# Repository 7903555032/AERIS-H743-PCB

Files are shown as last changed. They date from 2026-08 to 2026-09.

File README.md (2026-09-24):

# AERIS-H743 Hardware

# AERIS — Advanced Embedded Research & Intelligent Systems

A 6-layer STM32H743-based embedded development and flight-control/data-logging PCB designed as a practical hardware-design and PCB-layout project.

## Project Status

🚧 **Practice / Learning Project — Hardware Design Completed**

The PCB design phase is complete. This project is primarily a practical exercise to learn and apply professional PCB design concepts using KiCad, including schematic design, component selection, multi-layer stackup, component placement, power distribution, signal routing, high-speed interfaces, sensor interfacing, and design-rule checking.

This is **not a production-ready or professionally validated flight controller**. The design may contain mistakes or areas that require further review, optimization, and hardware validation.

The main goal of this project is to gain hands-on experience designing a complex **6-layer embedded PCB** from the ground up.

## Hardware Features

- STM32H743VIT6 — ARM Cortex-M7, up to 480 MHz
- 6-Layer PCB
- USB Type-C
- SPI / QSPI External Flash
- microSD via SDMMC
- ICM-42688-P IMU
- BME280 Environmental Sensor
- RTC
- INA219 Power Monitor
- CAN FD
- RS485
- GPS UART
- 4× ESC PWM Outputs
- SWD Debug Interface
- 3.3 V / 5 V Regulated Power Architecture

## PCB Architecture

- **L1 — Components + Critical Signals**
- **L2 — Ground Plane**
- **L3 — Power Distribution**
- **L4 — Signal Routing**
- **L5 — Ground Plane**
- **L6 — Bottom Signals + Selected Components**

## Communication Interfaces

- CAN FD
- RS485
- GPS UART
- USB
- SPI / QSPI
- I²C
- SDMMC

## PCB Design Goals

The main purpose of this project is to practice designing a relatively complex embedded PCB and understand how different parts of a real hardware system interact.

The design focuses on:

- 6-layer PCB architecture
- Power distribution
- Ground-plane design
- High-speed digital interfaces
- MCU placement and routing
- Sensor placement
- IMU placement considerations
- QSPI and SDMMC routing
- USB differential-pair routing
- CAN FD and RS485 interfaces
- ESC interfaces
- Thermal and mechanical considerations
- Custom KiCad symbols, footprints and 3D models
- PCB Design Rule Checking (DRC)
- Manufacturing preparation

## Project Structure

```text
AERIS-H743/
│
├── KiCAD/
│   └── AERIS-H743-PCB/
│       ├── AERIS-H743-PCB.kicad_pro
│       ├── AERIS-H743-PCB.kicad_sch
│       ├── AERIS-H743-PCB.kicad_pcb
│       ├── MCU_Core.kicad_sch
│       ├── POWER.kicad_sch
│       ├── Memory&Storage.kicad_sch
│       └── sensors.kicad_sch
│
├── Libraries/
│   ├── Symbols/
│   ├── Footprints.pretty/
│   └── 3D/
│
├── Documentation/
│
├── Datasheets/
│
└── README.md

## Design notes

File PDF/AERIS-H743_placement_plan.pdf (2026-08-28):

# AERIS-H743

## PCB component placement plan — pre-routing

Fabrication-oriented placement plan for the 6-layer, 5-inch-class quadcopter PCB. Zones and priorities are derived from the confirmed mechanical spec (160mm hole-to-hole diagonal, 46x46mm hub, 20mm arms) and the established schematic architecture. Anything not yet specified in the project (exact battery current, motor/ESC current draw, U1 switching frequency, firmware axis convention) is marked OPEN/NEEDS VERIFICATION rather than assumed.

# 1. Per-component placement table

Ref | Component | Zone | Orientation/relation | Reason
J1 | XT30 connector | Power entry | Board edge, cable exit pointing outward | First point of contact — needs external cable access
Q1 | AO3407A P-FET | Power entry | In line between J1 and F1, within 5mm of both | Reverse-polarity protection must be first in the chain, no detours
R1 | 10k gate pulldown | Power entry | Directly at Q1 gate pin | Minimize gate trace length
F1 | Fuse 2A PPTC | Power entry | In line, within 5mm of Q1 and R26 | Series element, keep the high-current path straight
D1 | SMF26A TVS | Power entry | Directly across the F1-R26 junction to nearest GND via | Needs shortest possible path to ground to clamp effectively
R26 | Shunt 20mOhm | Power entry | In line, Kelvin-sense traces to U10 kept short and symmetric | Current-sense accuracy depends on clean, undisturbed sense trace routing
C1, C2 | Buck input caps 10uF | Power conversion | Within 3mm of U1 VIN pin | High-frequency input decoupling, distance directly increases loop inductance
U1 | AP63205WU buck | Power conversion | Oriented so SW node/inductor loop is compact and away from IMU zone | Switching node is the primary EMI source on the board
L1 | Buck inductor | Power conversion | Immediately adjacent to U1 SW pin, shortest possible SW trace | SW node trace should be as short and wide as practical — high dv/dt
C3 | Buck output cap 22uF | Power conversion | Within 3mm of L1 output / U1 FB divider | Output ripple filtering, close to the node it filters
R2, R3 | FB divider | Power conversion | Tight to U1 FB pin, away from SW node/inductor | FB is a sensitive high-impedance node — noise pickup here destabilizes regulation
C4 | Bootstrap cap 100nF | Power conversion | Directly between U1 BOOT and SW pins | Bootstrap caps must be immediately adjacent to their pins by design
U9a | AP2112K-3.3 digital LDO | Power conversion | Between buck output and MCU zone | Shortens the +3V3 digital distribution path
U9b | AP7343-33W5-7 sensor LDO | Power conversion | Between buck output and IMU/sensor zone, physically separated from U9a | Keeps sensor rail regulation independent and close to what it feeds
C5a-d | LDO in/out caps 1uF | Power conversion | Directly at each LDO IN/OUT pin | Standard LDO stability requirement — distance affects transient response
U10 | INA226 | Power entry | Adjacent to R26, Kelvin sense traces direct | Sense accuracy depends on undisturbed direct connection to shunt
C7 | INA226 decoupling 100nF | Power entry | At U10 VCC pin | Standard IC decoupling
J2 | USB-C receptacle | USB zone | Board edge, connector shell grounded to nearest edge copper | Needs external cable access
U2 | USBLC6-2SC6 ESD | USB zone | Between J2 and the D+/D- trace path, within 3mm of J2 pins | ESD protection must intercept transients before the trace, at the connector
R4, R5 | USB series 22R | USB zone | In line between U2 and MCU USB pins | Standard USB series termination placement
R6, R7 | CC pulldowns 5.1k | USB zone | At J2 CC1/CC2 pins | Local to the pins they set
D2 | PMEG3020EH power-OR diode | Power entry | Between J2 VBUS and the +5V bus junction | Sits on the power path, not a signal path

Ref | Component | Zone | Orientation/relation | Reason
U3 | STM32H743VIT6 | MCU zone | Hub center, orientation set so QSPI/SDMMC face memory zone and USB pins face USB zone | Central position minimizes average trace length to every other zone — see MCU orientation note below
C-VDD x5 | 100nF VDD decoupling | MCU zone | One capacitor within 2mm of each of the 5 VDD pins, on the same layer where possible | High-frequency decoupling effectiveness drops sharply with distance — this is the single most important passive-placement rule on the board
C-bulk | 4.7uF VDD bulk | MCU zone | Within 5mm of the VDD pin cluster | Bulk capacitance can sit slightly further than the 100nF caps
C-VCAP1 , C-VCAP2 | 2.2uF VCAP caps | MCU zone | Directly at VCAP_1 and VCAP_2 pins, shortest possible traces, low-inductance via to GND | These supply the MCU core regulator — ST explicitly calls out low-ESR/short-trace requirement in AN4938
C6, C18 | VDDA decoupling 1uF/100nF | MCU zone | At VDDA pin, via FB1 ferrite | Analog supply — isolate from digital switching noise on the same rail
C13, C33 | VREF+ decoupling 1uF/100nF | MCU zone | At VREF+ pin | Same reasoning as VDDA
FB1 | Ferrite bead | MCU zone | In line between +3V3 and VDDA pin | Filters digital supply noise before it reaches the analog supply
SW1 | Reset button | MCU zone (edge-accessible) | Near board edge if possible for physical access during bring-up | You will press this a lot during firmware development
C-nrst | NRST filter 100nF | MCU zone | At NRST pin | Standard filter placement
SW2 | BOOT0 button | MCU zone (edge-accessible) | Near SWD header for convenient access during flashing | Used together with reset during bootloader entry
R8 | BOOT0 pulldown 10k | MCU zone | At BOOT0 pin | Standard
X1 | 25MHz HSE crystal | MCU zone | As close as physically possible to OSC_IN/OSC_OUT pins, symmetric trace lengths, guard-ringed with GND pour, no other signals routed nearby | Crystal traces are highly sensitive to parasitic capacitance and coupling — this is a hard placement rule, not a preference
C-hse1, C-hse2 | HSE load caps | MCU zone | Directly at crystal pins, symmetric placement | Asymmetric placement unbalances the oscillator loop
X2 | 32.768kHz LSE crystal | MCU zone | Same rules as X1, physically separated from X1 and from any switching supply | Low-frequency crystal is even more sensitive to coupling than HSE
C-lse1, C-lse2 | LSE load caps | MCU zone | Directly at crystal pins | Same as HSE
J3 | SWD header | SWD zone (edge-accessible) | Board edge, oriented for a programmer clip or pogo fixture | Needs physical access throughout bring-up and later debugging

Ref | Component | Zone | Orientation/relation | Reason
U4 | ICM-42688-P IMU | IMU zone | Hub center, offset toward the side away from power conversion, one axis aligned to arm 1 — OPEN/NEEDS VERIFICATION: confirm firmware axis convention before finalizing orientation | Most vibration- and noise-sensitive component on the board — see IMU placement note above
C23 | IMU decoupling 100nF | IMU zone | Directly at U4 VDD pin | Standard, but especially important for a sensitive analog/MEMS device
R14 | IMU CS pullup 10k | IMU zone | At U4 CS pin | Standard
U6 | BME280 | Other-sensor zone | MCU-adjacent, can tolerate closer proximity to digital signals than the IMU | Environmental sensor, not vibration-critical
C24 | BME280 decoupling 100nF | Other-sensor zone | At U6 VDD pin | Standard
U7 | DS3231MZ RTC | Other-sensor zone | MCU-adjacent, away from crystal X1/X2 to avoid frequency interference | RTC has its own timing crystal-equivalent internally — keep clear of the MCU crystals
C25, C26 | RTC decoupling | Other-sensor zone | At U7 VCC and VBAT pins | Standard
BT1 | CR1220 holder | Other-sensor zone | Accessible for battery replacement — consider board edge or a cutout | This is a user-serviceable part, unlike everything else on the board
R12, R13 | I2C1 pullups 4.7k | Other-sensor zone | Near the physical middle of the I2C1 bus run (U6/U7/U10), not at any single endpoint | Standard I2C pullup placement practice
U5 | W25Q128JVSIQ QSPI flash | Memory zone | MCU-adjacent, shortest practical QSPI trace length, length-matched CLK/IO0-3 | QSPI is a source-synchronous high-speed bus — trace length mismatch directly costs timing margin
C-flash | Flash decoupling 100nF | Memory zone | At U5 VCC pin | Standard
R-qspi2, R-qspi3 | QSPI IO2/IO3 pullups | Memory zone | Near U5, on the QSPI_IO2/IO3 nets | Standard
J4 | microSD socket | Memory zone (edge-accessible) | Board edge or accessible cutout for card insertion/removal, SDMMC traces kept short from MCU | Physical card access is a hard mechanical requirement, not optional
C21, C22 | microSD decoupling | Memory zone | At J4 VDD pin | Standard
R9-R13 | SDMMC pullups 47k | Memory zone | Near J4/SDMMC bus run | Standard

Ref | Component | Zone | Orientation/relation | Reason
U13 | MCP2515 (if used) or native FDCAN path | Comms zone | Near CAN connector J5, away from IMU zone | OPEN/NEEDS VERIFICATION: confirm final CAN architecture (native FDCAN vs earlier MCP2515 plan) before finalizing this row
U8 | SN65HVD230 CAN transceiver | Comms zone | Directly adjacent to J5 connector | Transceiver should sit as close as possible to the physical bus connector
C-can | CAN decoupling 100nF | Comms zone | At U8 VCC pin | Standard
R17 | CAN termination 120R (DNP) | Comms zone | Across J5 CANH/CANL, right at the connector | Termination belongs at the physical bus endpoint, not upstream
J5 | CANH/CANL header | Comms zone (edge-accessible) | Board edge | External bus connector
U11 | MAX3485 RS485 transceiver | Comms zone | Directly adjacent to J6 connector | Same reasoning as CAN transceiver
C-485 | RS485 decoupling 100nF | Comms zone | At U11 VCC pin | Standard
R18 | RS485 termination 120R (DNP) | Comms zone | Across J6 A/B, at the connector | Same as CAN termination
J6 | RS485 A/B header | Comms zone (edge-accessible) | Board edge | External bus connector
J7 | GPS header | Comms zone (top edge) | Top edge of hub, per original mechanical plan | Keeps GPS antenna cable routing away from motor/ESC arms — reduces EMI exposure
Ref | Component | Zone | Orientation/relation | Reason
J10-J13 | ESC signal pads x4 | Arm tips | At each arm tip, near the mounting hole | Motors and ESCs physically live here — no flexibility on this one
R19-R22 | ESC signal pulldowns 10k | Arm tips | At each J10-J13 pad | Local to the pin they protect
J8, J9 | Expansion headers | Hub edge, wherever space remains | Accessible edge, non-critical | Lowest placement priority — fill remaining space last
LED1-3 | Status LEDs | Hub edge, visible when assembled | Should be visible without disassembly | User-facing indicator, needs line of sight
SW3 | User button | Hub edge, physically accessible | Reachable without disassembly | Same reasoning as LEDs

# 2. Forbidden and problematic placements

Component/zone | Keep away from | Minimum practical separation | Consequence if ignored
IMU (U4) | U1 buck converter and L1 inductor | Maximum practical distance within the 46mm hub — realistically 15-20mm; OPEN/NEEDS VERIFICATION exact figure depends on U1 switching frequency (not yet specified) | Switching noise couples into IMU readings, causing bias drift and noisy attitude estimates — directly affects flight stability
IMU (U4) | Any high-current trace or pour, including the SW node copper | No shared copper layer directly beneath the IMU footprint | Magnetic field coupling from current-carrying copper corrupts gyroscope readings
X1, X2 crystals | Any digital switching signal (QSPI, SDMMC, USB, PWM) | No parallel routing within 3mm, no crossing on adjacent layers without a solid ground plane between them | Coupled noise causes clock jitter, which cascades into timing errors on every peripheral that depends on the system clock
USB differential pair | U1 SW node and buck inductor | Route on the opposite side of the MCU from the buck if possible | Switching noise injected into the USB pair causes enumeration failures or data errors, especially at USB high-speed rates
R26 shunt / INA226 Kelvin sense traces | Any other current-carrying trace running parallel | Dedicated, undisturbed sense trace pair, no shared copper with the power path itself | Sense accuracy degrades — you get an inaccurate current reading, defeating the purpose of the current-monitoring circuit
J5/J6 (CAN, RS485 connectors) | IMU zone and crystal zone | Opposite side of the hub where mechanically possible | External cable-borne noise/ESD events have a shorter, more direct coupling path to sensitive circuitry
J1 (battery connector) and Q1/F1/D1 | Board edge clearance | Standard fab-house minimum edge clearance for connectors, typically 0.5-1mm depending on your fab — confirm with JLCPCB before finalizing | Connector courtyard violates DFM rules, risking fabrication rejection or assembly issues
J4 (microSD socket) | Any component that would block the card ejection path | Physical clearance for the card and your fingers, not just the socket footprint | A card you cannot physically remove without desoldering something is a real, embarrassing failure mode

# 3. Routing-priority table (before you route anything)

Category | Nets | Priority | Requirement
Differential pair | USB_DP / USB_DM | Critical | Length-matched pair, controlled impedance per your stackup (see section 5), routed together with consistent spacing
High-speed single-ended, matched group | QSPI_CLK, QSPI_IO0-3 | Critical | Length-matched within the group, short and direct, minimal via count
High-speed single-ended, matched group | SDMMC_CK, SDMMC_CMD, SDMMC_D0-3 | Critical | Same reasoning as QSPI
Clock | HSE (X1), LSE (X2) crystal traces | Critical | Shortest possible, symmetric, guard-ringed with ground pour, isolated from all other signals
High-current power | +BATT path (J1 through Q1, F1, R26, to U1 VIN) | Critical | Wide traces or copper pour, sized for actual current draw — OPEN/NEEDS VERIFICATION: exact width depends on your final battery/current decision
Switching power | U1 SW node to L1 | Critical | Short, wide, minimal loop area — this is your primary EMI source
Sensitive analog | IMU SPI bus (CS, SCK, MOSI, MISO) | High | Short, direct, away from any switching or high-current trace on any layer
Sensitive analog | INA226 Kelvin sense pair | High | Dedicated undisturbed pair, see forbidden-placement table
Bus, shared | I2C1_SCL, I2C1_SDA | Medium | Standard routing, pullups placed mid-bus
Bus, differential-ish | CANH, CANL | Medium | Matched length, routed as a pair even though not strictly controlled-impedance
Bus, differential-ish | RS485 A, B | Medium | Same as CAN
UART | GPS TX/RX, RS485 TX/RX (MCU side) | Low | Standard single-ended routing
GPIO/control | ESC1-4 PWM, RGB LED, status LED, user button | Low | No special requirements beyond keeping clear of the critical categories above
Power distribution | +5V, +3V3, +3V3_SENSOR | High | Prefer plane/pour distribution over traces where the layer stack allows
Ground | GND | Critical | Solid plane, not routed as traces — see stackup strategy

# 4. 6-layer stackup strategy (JLC06161H-3313)

This is guidance based on the general structure of this stackup class (signal-ground-signal-power-ground-signal or similar 6-layer arrangements are standard for this JLCPCB offering) — OPEN/NEEDS VERIFICATION: pull the exact per-layer assignment and dielectric heights from JLCPCB's current stackup documentation for JLC06161H-3313 before finalizing impedance-controlled trace widths, since those numbers directly depend on it and I have not independently verified the current spec sheet in this conversation.

Layer | Typical assignment for this class | Placement implication
L1 (top) | Components + primary signals (USB diff pair, QSPI, SDMMC, SPI1) | Keep high-speed signals here where possible, referenced to L2 ground
L2 | Ground plane | Never split, even under the buck converter — this is the return path for every signal on L1
L3 | Power plane(s) — split pour for +5V/+3V3/+3V3_SENSOR | Keep the +3V3_SENSOR pour physically separated from +3V3 digital, moated, single connection point back to the LDO
L4 | Ground plane | Second ground reference, improves return path for L5 signals
L5 | Secondary signals (I2C1, UART, GPIO, ESC PWM, CAN/RS485) | Lower-speed signals that do not need L1-quality reference
L6 (bottom) | Components + remaining signals | Keep the buck converter switching loop confined to as few layers as possible to minimize radiated loop area

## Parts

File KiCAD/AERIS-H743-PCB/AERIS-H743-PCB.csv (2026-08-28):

Reference | Qty | Value | DNP | Exclude from BOM | Exclude from Board | Footprint | Datasheet
BT1 | 1 | Battery |  |  |  | Battery:BatteryHolder_Keystone_1058_1x2032
C1,C2 | 2 | 10uF |  |  |  | Capacitor_SMD:C_0805_2012Metric
C3 | 1 | 22uF |  |  |  | Capacitor_SMD:C_0805_2012Metric
C4,C7 | 2 | 100nF |  |  |  | Capacitor_SMD:C_0805_2012Metric
C5,C8,C10,C16,C18,C19,C21,C22,C23,C24,C25,C27,C28,C29,C30,C31,C32,C33,C34 | 19 | 100nF |  |  |  | Capacitor_SMD:C_0603_1608Metric
C5a1,C5b1,C5c1,C5d1 | 4 | 1uF |  |  |  | Capacitor_SMD:C_0805_2012Metric
C6,C13,C26 | 3 | 1uF |  |  |  | Capacitor_SMD:C_0603_1608Metric
C9 | 1 | 4.7uF |  |  |  | Capacitor_SMD:C_0805_2012Metric
C11,C14 | 2 | 3.9pF |  |  |  | Capacitor_SMD:C_0603_1608Metric
C12,C15 | 2 | 2.2uF |  |  |  | Capacitor_SMD:C_0603_1608Metric
C17,C20 | 2 | 1.5pF |  |  |  | Capacitor_SMD:C_0603_1608Metric
D1 | 1 | SMBJ12A |  |  |  | Library:DIOM4336X265N
D2 | 1 | B0530W |  |  |  | Library:DIO_B0530W
D4 | 1 | LED2 |  |  |  | LED_SMD:LED_0603_1608Metric
D5 | 1 | LED1 |  |  |  | LED_SMD:LED_0603_1608Metric
D6 | 1 | LED_RGB |  |  |  | LED_SMD:LED_RGB_5050-6
F1 | 1 | Fuse |  |  |  | Fuse:Fuse_1206_3216Metric
FB1 | 1 | FerriteBead_Small |  |  |  | Inductor_SMD:L_0603_1608Metric
J1 | 1 | XT30PW-M |  |  |  | Library:XT30PW-M
J2 | 1 | USB_C_Receptacle_USB2.0_16P |  |  |  | Connector_USB:USB_C_Receptacle_GCT_USB4085 | https://www.usb.org/sites/default/files/documents/usb_type-c.zip
J3 | 1 | Conn_01x06 |  |  |  | Connector_PinHeader_1.00mm:PinHeader_2x03_P1.00mm_Vertical
J4 | 1 | 1040310811 |  |  |  | Library:104031-0811_MOL
J5,J6 | 2 | Conn_01x02_Pin |  |  |  | Connector_PinHeader_2.54mm:PinHeader_1x02_P2.54mm_Vertical
J7 | 1 | Conn_01x04_Pin |  |  |  | Connector_PinHeader_2.54mm:PinHeader_1x04_P2.54mm_Vertical
J10 | 1 | ESC1 |  |  |  | Connector_PinHeader_2.54mm:PinHeader_1x03_P2.54mm_Vertical
J11 | 1 | ESC2 |  |  |  | Connector_PinHeader_2.54mm:PinHeader_1x03_P2.54mm_Vertical
J12 | 1 | ESC3 |  |  |  | Connector_PinHeader_2.54mm:PinHeader_1x03_P2.54mm_Vertical
J13 | 1 | ESC4 |  |  |  | Connector_PinHeader_2.54mm:PinHeader_1x03_P2.54mm_Vertical
L1 | 1 | 4.7uH |  |  |  | Inductor_SMD:L_1210_3225Metric
Q1 | 1 | Q_PMOS_GSD |  |  |  | Package_TO_SOT_SMD:SOT-23
R1,R3 | 2 | 10K |  |  |  | Resistor_SMD:R_0603_1608Metric
R2 | 1 | 56K |  |  |  | Resistor_SMD:R_0603_1608Metric
R4,R5 | 2 | 22 |  |  |  | Resistor_SMD:R_0603_1608Metric
R6,R7 | 2 | 5.1K |  |  |  | Resistor_SMD:R_0603_1608Metric
R8 | 1 | 10kohm |  |  |  | Resistor_SMD:R_0603_1608Metric
R9 | 1 | 0 |  |  |  | Resistor_SMD:R_0603_1608Metric
R10,R11,R17 | 3 | 10k |  |  |  | Resistor_SMD:R_0603_1608Metric
R12,R13,R14,R15,R16 | 5 | 47k |  |  |  | Resistor_SMD:R_0603_1608Metric
R18,R19 | 2 | 4.7k |  |  |  | Resistor_SMD:R_0603_1608Metric
R20,R21 | 2 | 120 ohm DNP |  |  |  | Resistor_SMD:R_0603_1608Metric
R22,R25,R30,R32 | 4 | 330 ohm |  |  |  | Resistor_SMD:R_0603_1608Metric
R23 | 1 | 10 Kohm (pulldown) |  |  |  | Resistor_SMD:R_0603_1608Metric
R24 | 1 | 10Kohm (PullDown) |  |  |  | Resistor_SMD:R_0603_1608Metric
R26 | 1 | 20m ohm |  |  |  | Resistor_SMD:R_2512_6332Metric
R27,R29 | 2 | 10kohm(PD) |  |  |  | Resistor_SMD:R_0603_1608Metric
R28 | 1 | 220ohm |  |  |  | Resistor_SMD:R_0603_1608Metric
R31 | 1 | 10Kohm(PU) |  |  |  | Resistor_SMD:R_0603_1608Metric
SW1,SW2,SW3 | 3 | SW_Push |  |  |  | Button_Switch_SMD:SW_SPST_B3U-1000P
U1 | 1 | TPS563201DDCR |  |  |  | Library:SOT95P280X110-6N
U2 | 1 | USBLC6-2SC6 |  |  |  | Library:SOT95P280X145-6N
U3 | 1 | STM32H743VITx |  |  |  | Package_QFP:LQFP-100_14x14mm_P0.5mm | https://www.st.com/resource/en/datasheet/stm32h743vi.pdf
U4 | 1 | ICM-42688-P |  |  |  | Package_LGA:LGA-14_3x2.5mm_P0.5mm_LayoutBorder3x4y
U5 | 1 | W25Q128JVS |  |  |  | Package_SO:SOIC-8_5.3x5.3mm_P1.27mm | https://www.winbond.com/resource-files/w25q128jv_dtr%20revc%2003272018%20plus.pdf
U6 | 1 | BME280 |  |  |  | Package_LGA:Bosch_LGA-8_2.5x2.5mm_P0.65mm_ClockwisePinNumbering | https://www.bosch-sensortec.com/media/boschsensortec/downloads/datasheets/bst-bme280-ds002.pdf
U7 | 1 | DS3231MZ |  |  |  | Package_SO:SOIC-8_3.9x4.9mm_P1.27mm | http://datasheets.maximintegrated.com/en/ds/DS3231M.pdf
U8 | 1 | SN65HVD230 |  |  |  | Package_SO:SOIC-8_3.9x4.9mm_P1.27mm | http://www.ti.com/lit/ds/symlink/sn65hvd230.pdf
U9A1 | 1 | AP2112K-3.3 |  |  |  | Package_TO_SOT_SMD:SOT-23-5 | https://www.diodes.com/assets/Datasheets/AP2112.pdf
U9B1 | 1 | AP2112K-3.3 |  |  |  | Library:SOT95P285X145-5N | https://www.diodes.com/assets/Datasheets/AP2112.pdf
U10 | 1 | INA226 |  |  |  | Package_SO:TSSOP-10_3x3mm_P0.5mm | http://www.ti.com/lit/ds/symlink/ina226.pdf
U11 | 1 | MAX3485 |  |  |  | Package_SO:SOIC-8_3.9x4.9mm_P1.27mm | https://datasheets.maximintegrated.com/en/ds/MAX3483-MAX3491.pdf
Y1 | 1 | 25 MHz |  |  |  | Crystal:Crystal_SMD_3225-4Pin_3.2x2.5mm
Y2 | 1 | 32.768KHz |  |  |  | Crystal:Crystal_SMD_3215-2Pin_3.2x1.5mm

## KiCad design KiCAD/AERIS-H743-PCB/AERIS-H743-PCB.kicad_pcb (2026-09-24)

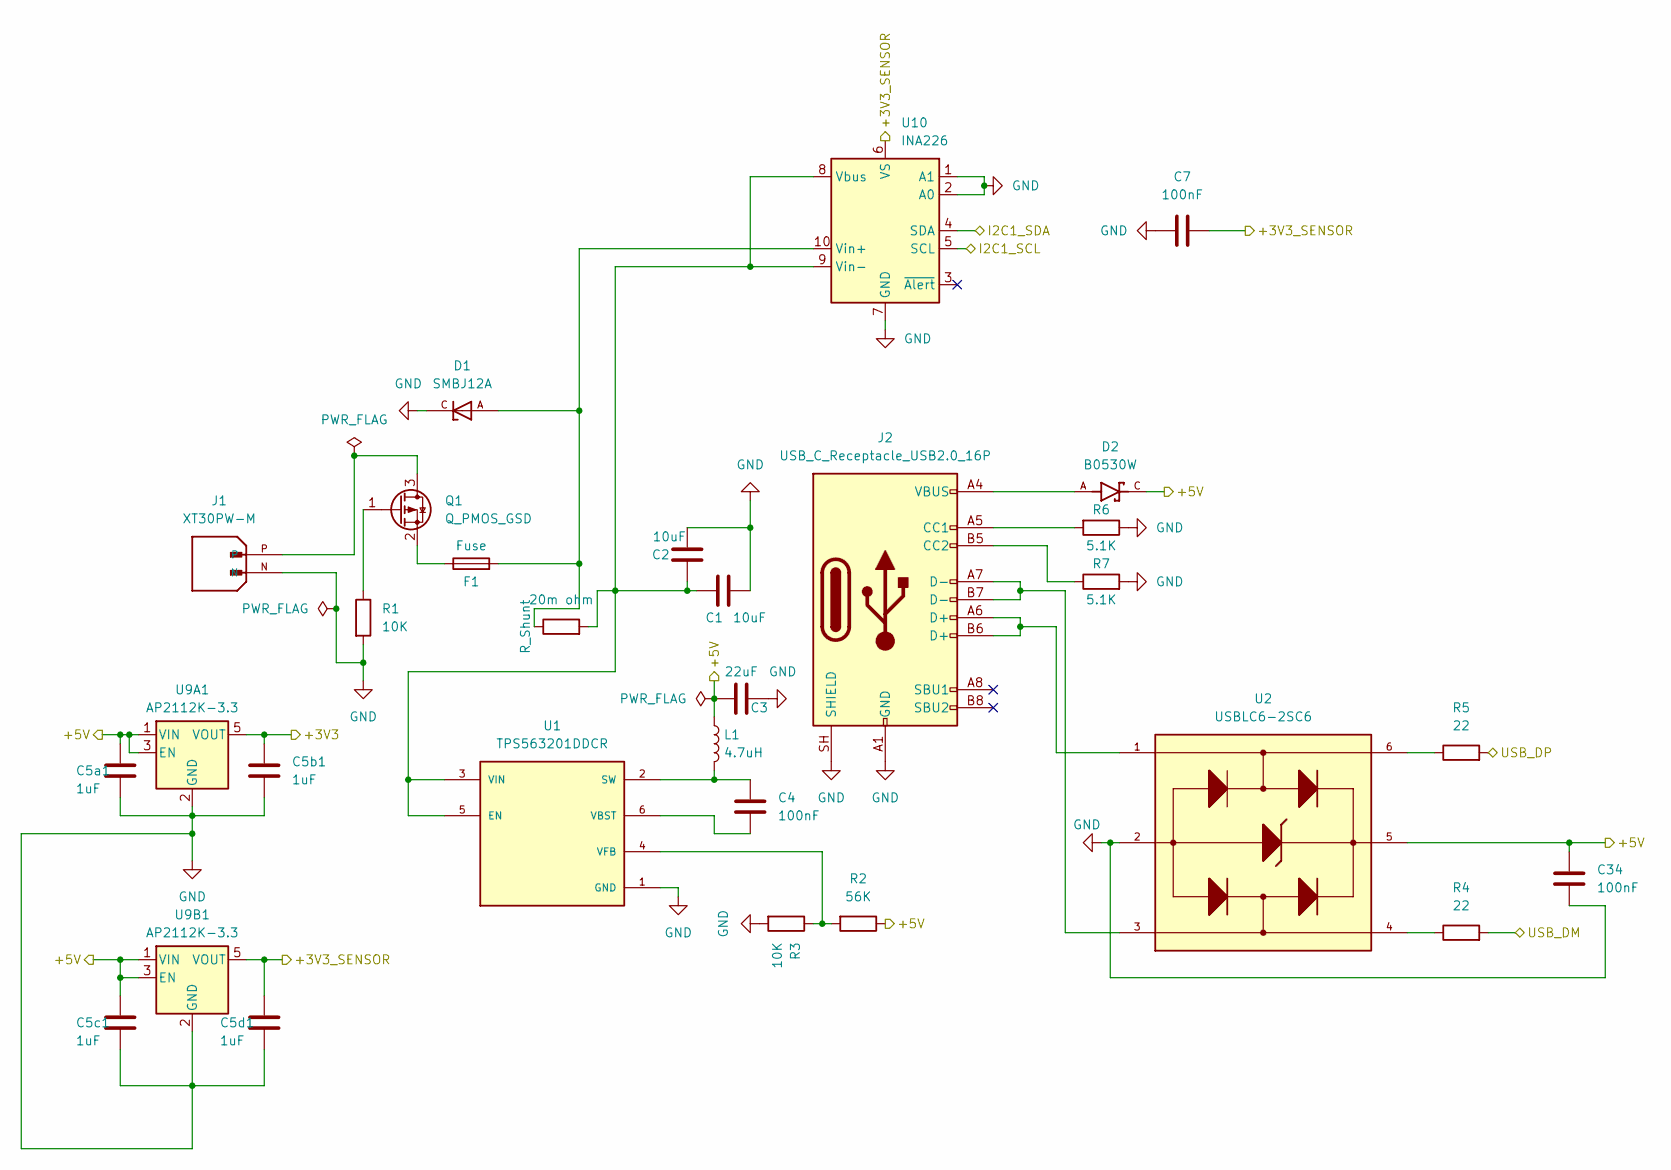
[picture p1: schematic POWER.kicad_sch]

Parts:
C1, C2: 10uF; C_0805_2012Metric
C3: 22uF; C_0805_2012Metric
C4, C7: 100nF; C_0805_2012Metric
C5a1, C5b1, C5c1, C5d1: 1uF; C_0805_2012Metric
C34: 100nF; C_0603_1608Metric
D1: SMBJ12A; DIOM4336X265N; PARTREV F2102
D2: B0530W; DIO_B0530W; PARTREV J2112
F1: Fuse; Fuse_1206_3216Metric
J1: XT30PW-M; PARTREV 1.2
J2: USB_C_Receptacle_USB2.0_16P; USB_C_Receptacle_GCT_USB4085
L1: 4.7uH; L_1210_3225Metric
Q1: Q_PMOS_GSD; SOT-23
R1, R3: 10K; R_0603_1608Metric
R2: 56K; R_0603_1608Metric
R4, R5: 22; R_0603_1608Metric
R6, R7: 5.1K; R_0603_1608Metric
R26: 20m ohm; R_2512_6332Metric
U1: TPS563201DDCR; SOT95P280X110-6N; PARTREV December 2015
U2: USBLC6-2SC6; SOT95P280X145-6N
U9A1: AP2112K-3.3; SOT-23-5
U9B1: AP2112K-3.3; SOT95P285X145-5N
U10: INA226; TSSOP-10_3x3mm_P0.5mm

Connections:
/3.3: C5b1.1, U9A1.5 (VOUT); also elsewhere on the board
/3.3_Sensor: C5d1.1, C7.1, U9B1.5 (VOUT), U10.6 (VS); also elsewhere on the board
/I2C1_SCL: U10.5 (SCL); also elsewhere on the board
/I2C1_SDA: U10.4 (SDA); also elsewhere on the board
/USB_DM: R4.2; also elsewhere on the board
/USB_DP: R5.2; also elsewhere on the board
unnamed: D2.A, J2.A4 (VBUS), J2.A9 (VBUS), J2.B4 (VBUS), J2.B9 (VBUS)
unnamed: J2.A5 (CC1), R6.2
unnamed: J2.B5 (CC2), R7.1
unnamed 66: J2.A6 (D+), J2.B6 (D+), U2.1; also elsewhere on the board
unnamed: J1.P, Q1.3 (D)
unnamed: Q1.1 (G), R1.1
unnamed: F1.1, Q1.2 (S)
unnamed 73: R5.1, U2.6; also elsewhere on the board
unnamed 74: C1.1, C2.2, R26.2, U1.3 (VIN), U1.5 (EN), U10.8 (Vbus), U10.9 (Vin-); also elsewhere on the board
unnamed: C4.1, L1.2, U1.2 (SW)
unnamed: C4.2, U1.6 (VBST)
unnamed: R2.2, R3.1, U1.4 (VFB)
unnamed 81: D1.A, F1.2, R26.1, U10.10 (Vin+); also elsewhere on the board

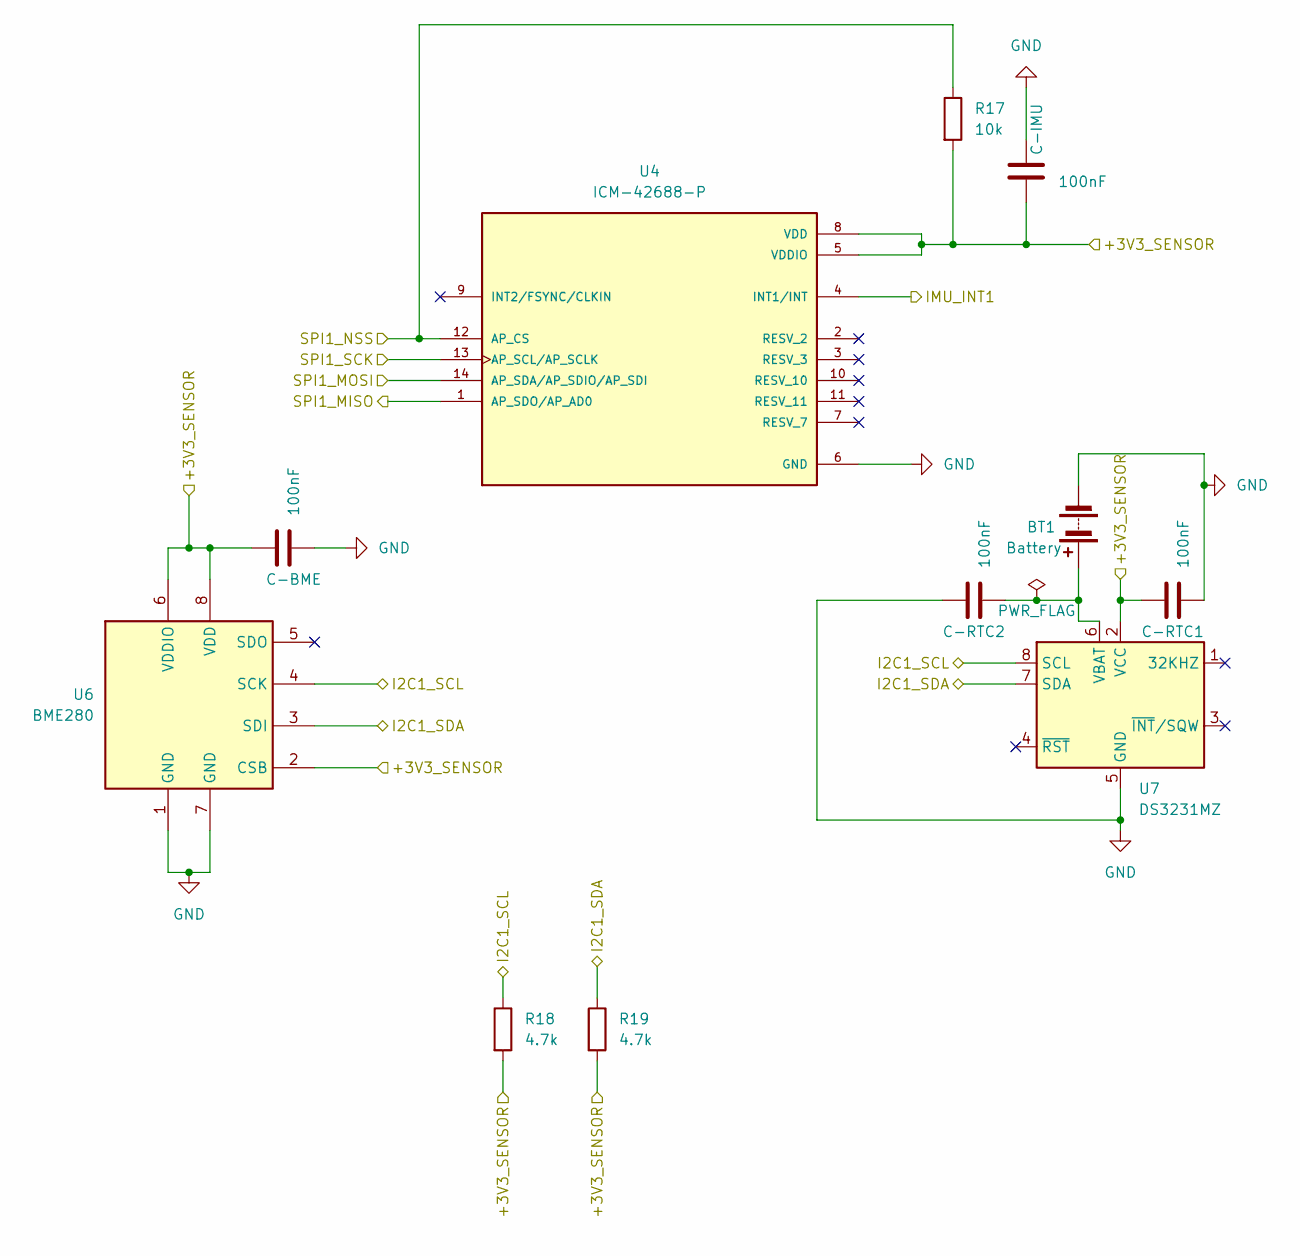
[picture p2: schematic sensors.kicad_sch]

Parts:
BT1: Battery; BatteryHolder_Keystone_1058_1x2032
C27, C28, C29, C30: 100nF; C_0603_1608Metric
R17: 10k; R_0603_1608Metric
R18, R19: 4.7k; R_0603_1608Metric
U4: ICM-42688-P; LGA-14_3x2.5mm_P0.5mm_LayoutBorder3x4y; PARTREV 1.2
U6: BME280; Bosch_LGA-8_2.5x2.5mm_P0.65mm_ClockwisePinNumbering
U7: DS3231MZ; SOIC-8_3.9x4.9mm_P1.27mm

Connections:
/3.3_Sensor: C27.2, C28.1, C29.1, R17.2, R18.2, R19.2, U4.5 (VDDIO), U4.8 (VDD), U6.2 (CSB), U6.6 (VDDIO), U6.8 (VDD), U7.2 (VCC); also elsewhere on the board
/I2C1_SCL: R18.1, U6.4 (SCK), U7.8 (SCL); also elsewhere on the board
/I2C1_SDA: R19.1, U6.3 (SDI), U7.7 (SDA); also elsewhere on the board
/IMU_INT1: U4.4 (INT1/INT); also elsewhere on the board
/MCU_Core/SPI1_MISO: U4.1 (AP_SDO/AP_AD0); also elsewhere on the board
/MCU_Core/SPI1_MOSI: U4.14 (AP_SDA/AP_SDIO/AP_SDI); also elsewhere on the board
/MCU_Core/SPI1_NSS: R17.1, U4.12 (AP_CS); also elsewhere on the board
/MCU_Core/SPI1_SCK: U4.13 (AP_SCL/AP_SCLK); also elsewhere on the board
unnamed: BT1.1 (+), C30.2, U7.6 (VBAT)

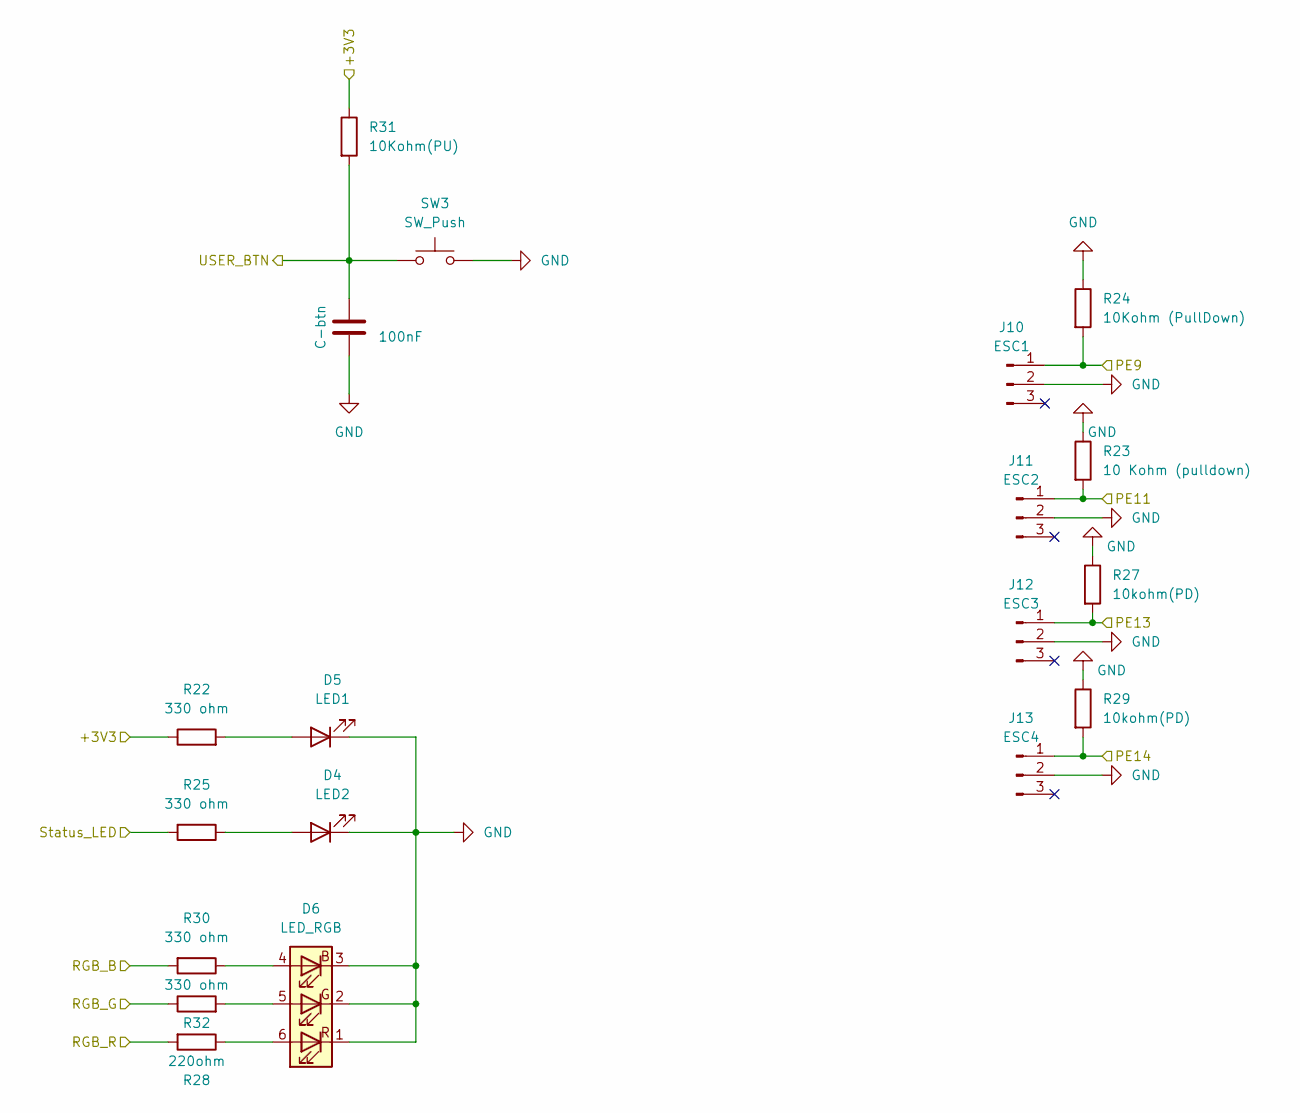
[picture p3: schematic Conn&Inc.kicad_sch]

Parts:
C33: 100nF; C_0603_1608Metric
D4: LED2; LED_0603_1608Metric
D5: LED1; LED_0603_1608Metric
D6: LED_RGB; LED_RGB_5050-6
J10: ESC1; PinHeader_1x03_P2.54mm_Vertical
J11: ESC2; PinHeader_1x03_P2.54mm_Vertical
J12: ESC3; PinHeader_1x03_P2.54mm_Vertical
J13: ESC4; PinHeader_1x03_P2.54mm_Vertical
R22, R25, R30, R32: 330 ohm; R_0603_1608Metric
R23: 10 Kohm (pulldown); R_0603_1608Metric
R24: 10Kohm (PullDown); R_0603_1608Metric
R27, R29: 10kohm(PD); R_0603_1608Metric
R28: 220ohm; R_0603_1608Metric
R31: 10Kohm(PU); R_0603_1608Metric
SW3: SW_Push; SW_SPST_B3U-1000P

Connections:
/3.3: R22.1, R31.1; also elsewhere on the board
/PE9: J10.1, R24.2; also elsewhere on the board
/PE11: J11.1, R23.2; also elsewhere on the board
/PE13: J12.1, R27.2; also elsewhere on the board
/PE14: J13.1, R29.2; also elsewhere on the board
/RGB_B: R30.2; also elsewhere on the board
/RGB_G: R32.1; also elsewhere on the board
/RGB_R: R28.2; also elsewhere on the board
/S_LED: R25.2; also elsewhere on the board
/U_BTN: C33.1, R31.2, SW3.1; also elsewhere on the board
unnamed: D4.2 (A), R25.1
unnamed: D5.2 (A), R22.2
unnamed: D6.4 (BA), R30.1
unnamed: D6.5 (GA), R32.2
unnamed: D6.6 (RA), R28.1

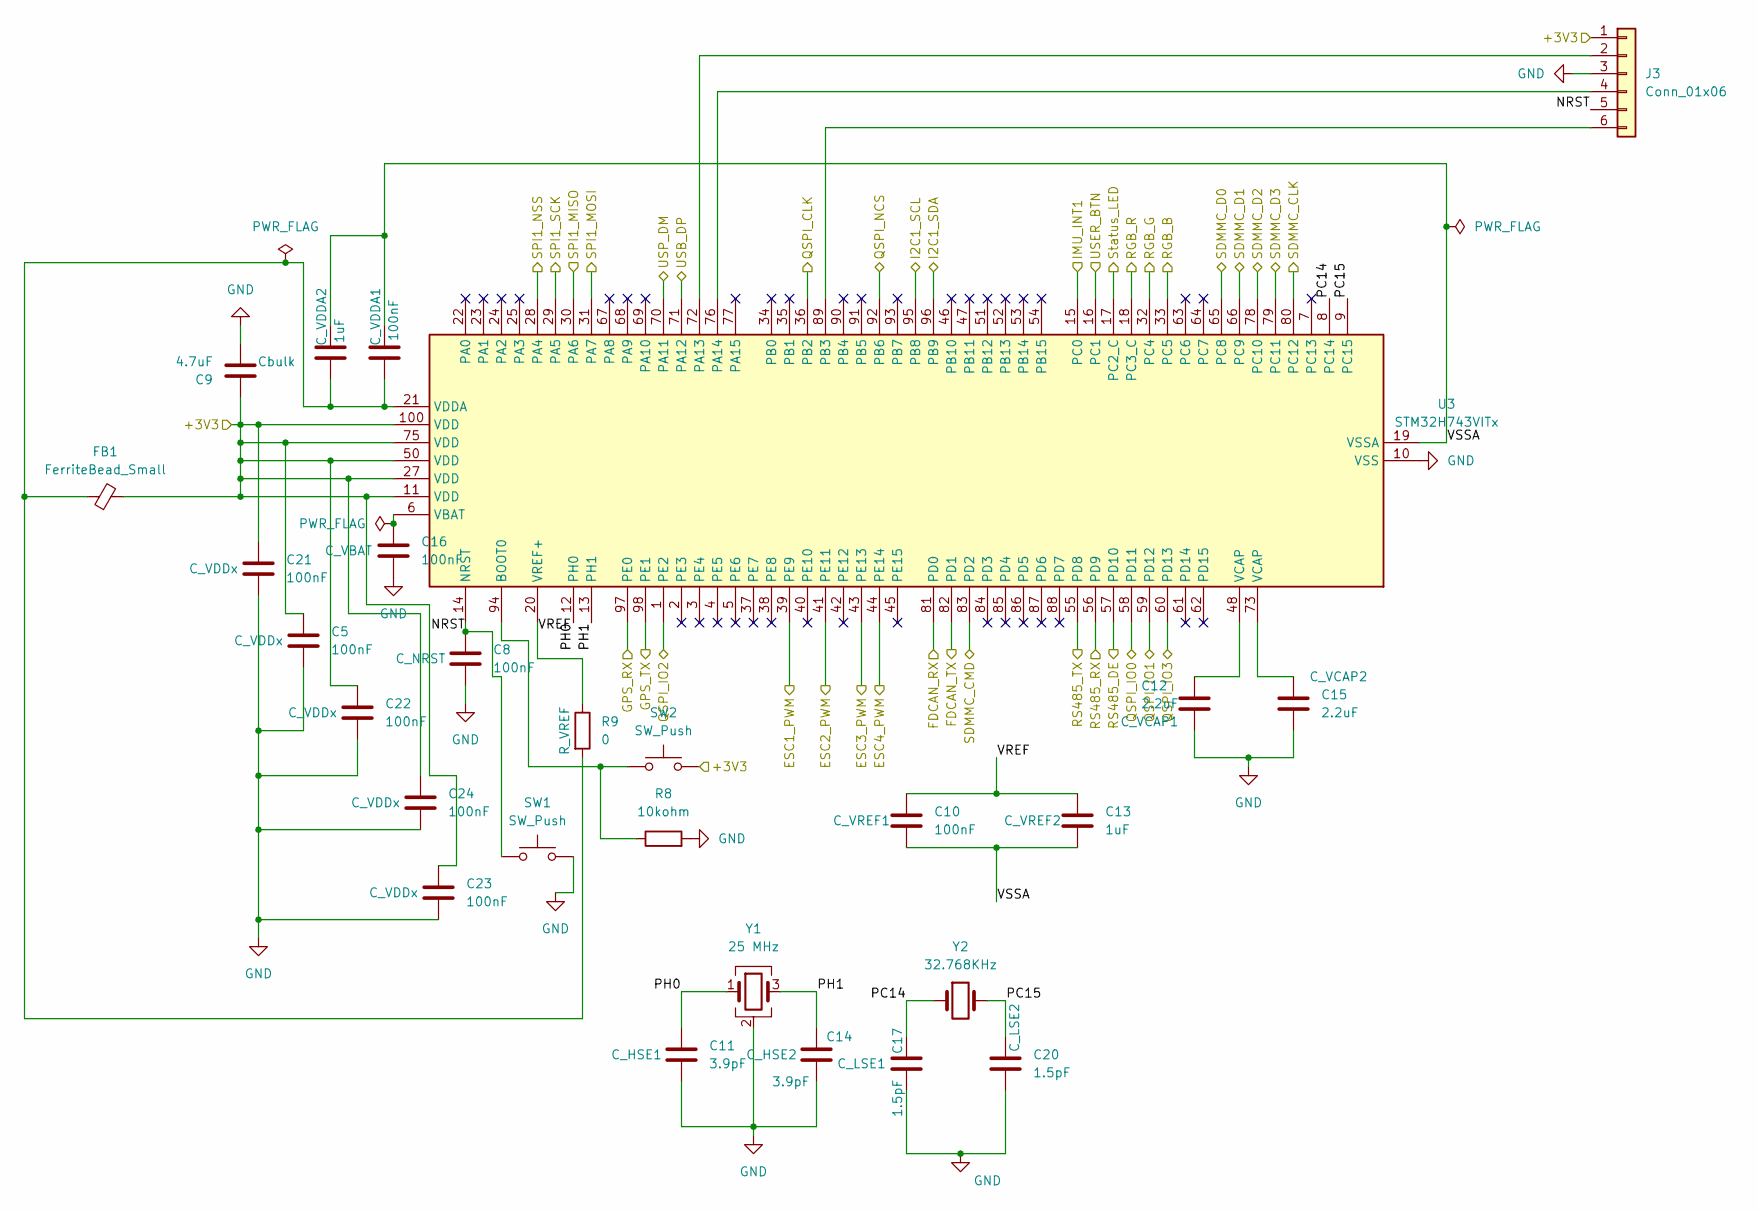
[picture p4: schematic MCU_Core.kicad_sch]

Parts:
C5, C8, C10, C16, C18, C21, C22, C23, C24: 100nF; C_0603_1608Metric
C6, C13: 1uF; C_0603_1608Metric
C9: 4.7uF; C_0805_2012Metric
C11, C14: 3.9pF; C_0603_1608Metric
C12, C15: 2.2uF; C_0603_1608Metric
C17, C20: 1.5pF; C_0603_1608Metric
FB1: FerriteBead_Small; L_0603_1608Metric
J3: Conn_01x06; PinHeader_2x03_P1.00mm_Vertical
R8: 10kohm; R_0603_1608Metric
R9: 0; R_0603_1608Metric
SW1, SW2: SW_Push; SW_SPST_B3U-1000P
U3: STM32H743VITx; LQFP-100_14x14mm_P0.5mm
Y1: 25 MHz; Crystal_SMD_3225-4Pin_3.2x2.5mm
Y2: 32.768KHz; Crystal_SMD_3215-2Pin_3.2x1.5mm

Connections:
/3.3: C5.1, C9.1, C21.1, C22.1, C23.1, C24.1, FB1.2, J3.1, SW2.2, U3.11 (VDD), U3.27 (VDD), U3.50 (VDD), U3.75 (VDD), U3.100 (VDD); also elsewhere on the board
/F_RX: U3.81 (PD0); also elsewhere on the board
/F_TX: U3.82 (PD1); also elsewhere on the board
/GPS_RX: U3.97 (PE0); also elsewhere on the board
/GPS_TX: U3.98 (PE1); also elsewhere on the board
/I2C1_SCL: U3.95 (PB8); also elsewhere on the board
/I2C1_SDA: U3.96 (PB9); also elsewhere on the board
/IMU_INT1: U3.15 (PC0); also elsewhere on the board
/MCU_Core/NRST: C8.1, J3.5, SW1.1, U3.14 (NRST)
/MCU_Core/PC14: C17.1, U3.8 (PC14), Y2.1; also elsewhere on the board
/MCU_Core/PC15: C20.1, U3.9 (PC15), Y2.2
/MCU_Core/PH0: C11.1, U3.12 (PH0), Y1.1
/MCU_Core/PH1: C14.1, U3.13 (PH1), Y1.3
/MCU_Core/SPI1_MISO: U3.30 (PA6); also elsewhere on the board
/MCU_Core/SPI1_MOSI: U3.31 (PA7); also elsewhere on the board
/MCU_Core/SPI1_NSS: U3.28 (PA4); also elsewhere on the board
/MCU_Core/SPI1_SCK: U3.29 (PA5); also elsewhere on the board
/MCU_Core/VREF: C10.1, C13.1, R9.1, U3.20 (VREF+)
/MCU_Core/VSSA: C6.1, C10.2, C13.2, C18.2, U3.19 (VSSA)
/PE9: U3.39 (PE9); also elsewhere on the board
/PE11: U3.41 (PE11); also elsewhere on the board
/PE13: U3.43 (PE13); also elsewhere on the board
/PE14: U3.44 (PE14); also elsewhere on the board
/QSPI_CLK: U3.36 (PB2); also elsewhere on the board
/QSPI_IO0: U3.58 (PD11); also elsewhere on the board
/QSPI_IO1: U3.59 (PD12); also elsewhere on the board
/QSPI_IO2: U3.1 (PE2); also elsewhere on the board
/QSPI_IO3: U3.60 (PD13); also elsewhere on the board
/QSPI_NCS: U3.92 (PB6); also elsewhere on the board
/RGB_B: U3.33 (PC5); also elsewhere on the board
/RGB_G: U3.32 (PC4); also elsewhere on the board
/RGB_R: U3.18 (PC3_C); also elsewhere on the board
/RS485_DE: U3.57 (PD10); also elsewhere on the board
/RS485_RX: U3.56 (PD9); also elsewhere on the board
/RS485_TX: U3.55 (PD8); also elsewhere on the board
/SDMMC_CLK: U3.80 (PC12); also elsewhere on the board
/SDMMC_CMD: U3.83 (PD2); also elsewhere on the board
/SDMMC_D0: U3.65 (PC8); also elsewhere on the board
/SDMMC_D1: U3.66 (PC9); also elsewhere on the board
/SDMMC_D2: U3.78 (PC10); also elsewhere on the board
/SDMMC_D3: U3.79 (PC11); also elsewhere on the board
/S_LED: U3.17 (PC2_C); also elsewhere on the board
/USB_DM: U3.70 (PA11); also elsewhere on the board
/USB_DP: U3.71 (PA12); also elsewhere on the board
/U_BTN: U3.16 (PC1); also elsewhere on the board
unnamed: C12.1, U3.48 (VCAP)
unnamed: C15.1, U3.73 (VCAP)
unnamed: J3.2, U3.72 (PA13)
unnamed: J3.4, U3.76 (PA14)
unnamed: J3.6, U3.89 (PB3)
unnamed: R8.1, SW2.1, U3.94 (BOOT0)
unnamed: C16.1, U3.6 (VBAT)
unnamed: C6.2, C18.1, FB1.1, R9.2, U3.21 (VDDA)

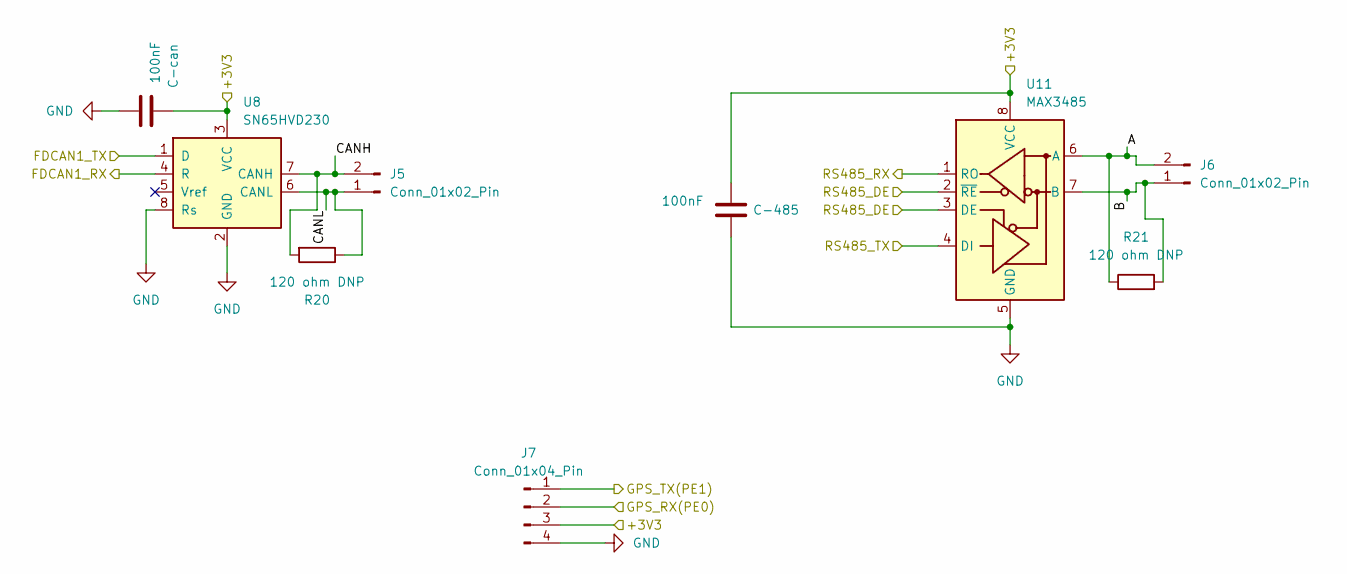
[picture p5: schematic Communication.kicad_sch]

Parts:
C31, C32: 100nF; C_0603_1608Metric
J5, J6: Conn_01x02_Pin; PinHeader_1x02_P2.54mm_Vertical
J7: Conn_01x04_Pin; PinHeader_1x04_P2.54mm_Vertical
R20, R21: 120 ohm DNP; R_0603_1608Metric
U8: SN65HVD230; SOIC-8_3.9x4.9mm_P1.27mm
U11: MAX3485; SOIC-8_3.9x4.9mm_P1.27mm

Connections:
/3.3: C31.2, C32.2, J7.3, U8.3 (VCC), U11.8 (VCC); also elsewhere on the board
/COMMUNICATION/A: J6.2, R21.1, U11.6 (A)
/COMMUNICATION/B: J6.1, R21.2, U11.7 (B)
/COMMUNICATION/CANH: J5.2, R20.2, U8.7 (CANH)
/COMMUNICATION/CANL: J5.1, R20.1, U8.6 (CANL)
/F_RX: U8.4 (R); also elsewhere on the board
/F_TX: U8.1 (D); also elsewhere on the board
/GPS_RX: J7.2; also elsewhere on the board
/GPS_TX: J7.1; also elsewhere on the board
/RS485_DE: U11.2 (~RE), U11.3 (DE); also elsewhere on the board
/RS485_RX: U11.1 (RO); also elsewhere on the board
/RS485_TX: U11.4 (DI); also elsewhere on the board

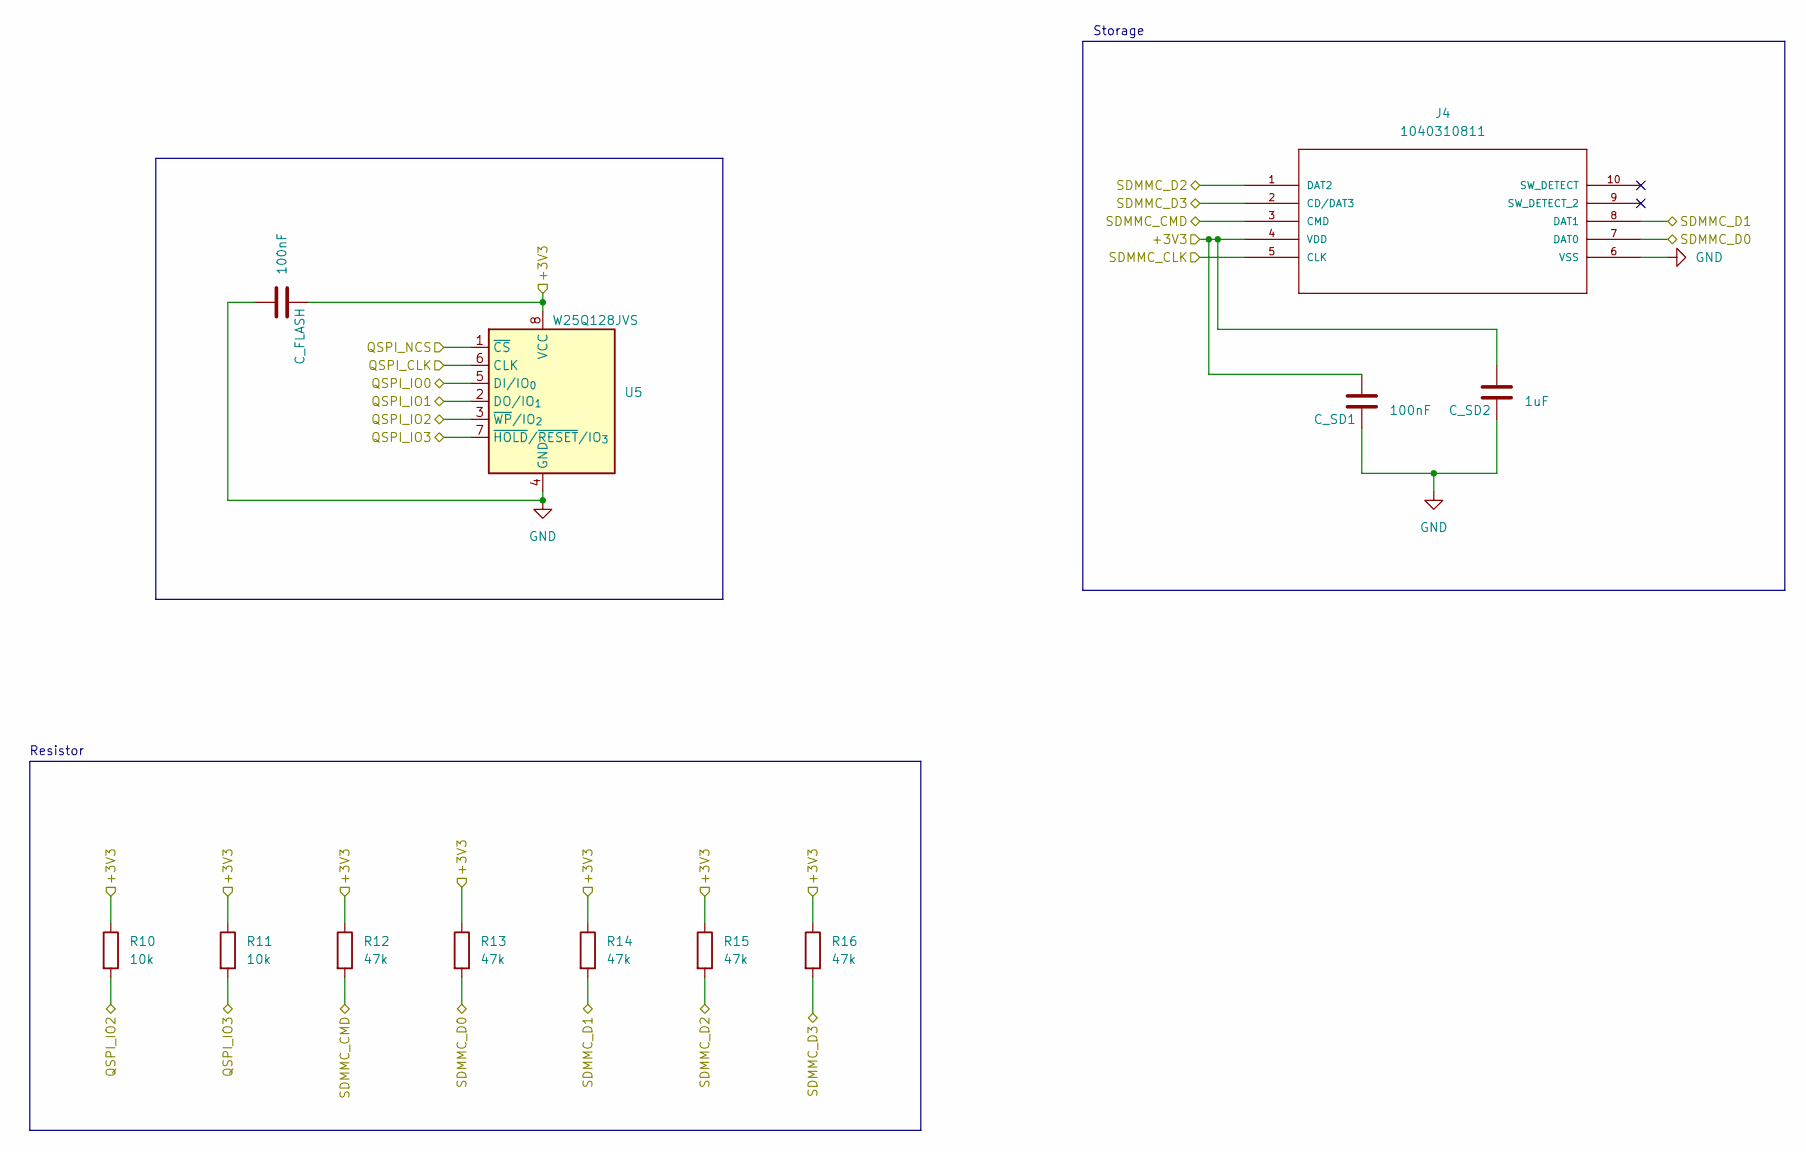
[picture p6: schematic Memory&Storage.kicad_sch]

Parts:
C19, C25: 100nF; C_0603_1608Metric
C26: 1uF; C_0603_1608Metric
J4: 1040310811; 104031-0811_MOL; MANUFACTURER_PART_NUMBER 1040310811
R10, R11: 10k; R_0603_1608Metric
R12, R13, R14, R15, R16: 47k; R_0603_1608Metric
U5: W25Q128JVS; SOIC-8_5.3x5.3mm_P1.27mm

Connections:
/3.3: C19.2, C25.1, C26.1, J4.4 (VDD), R10.1, R11.1, R12.1, R13.1, R14.1, R15.1, R16.1, U5.8 (VCC); also elsewhere on the board
/QSPI_CLK: U5.6 (CLK); also elsewhere on the board
/QSPI_IO0: U5.5 (DI/IO_{0}); also elsewhere on the board
/QSPI_IO1: U5.2 (DO/IO_{1}); also elsewhere on the board
/QSPI_IO2: R10.2, U5.3 (~WP/IO_{2}); also elsewhere on the board
/QSPI_IO3: R11.2, U5.7 (~HOLD/~RESET/IO_{3}); also elsewhere on the board
/QSPI_NCS: U5.1 (~CS); also elsewhere on the board
/SDMMC_CLK: J4.5 (CLK); also elsewhere on the board
/SDMMC_CMD: J4.3 (CMD), R12.2; also elsewhere on the board
/SDMMC_D0: J4.7 (DAT0), R13.2; also elsewhere on the board
/SDMMC_D1: J4.8 (DAT1), R14.2; also elsewhere on the board
/SDMMC_D2: J4.1 (DAT2), R15.2; also elsewhere on the board
/SDMMC_D3: J4.2 (CD/DAT3), R16.2; also elsewhere on the board

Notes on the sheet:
Storage
Resistor

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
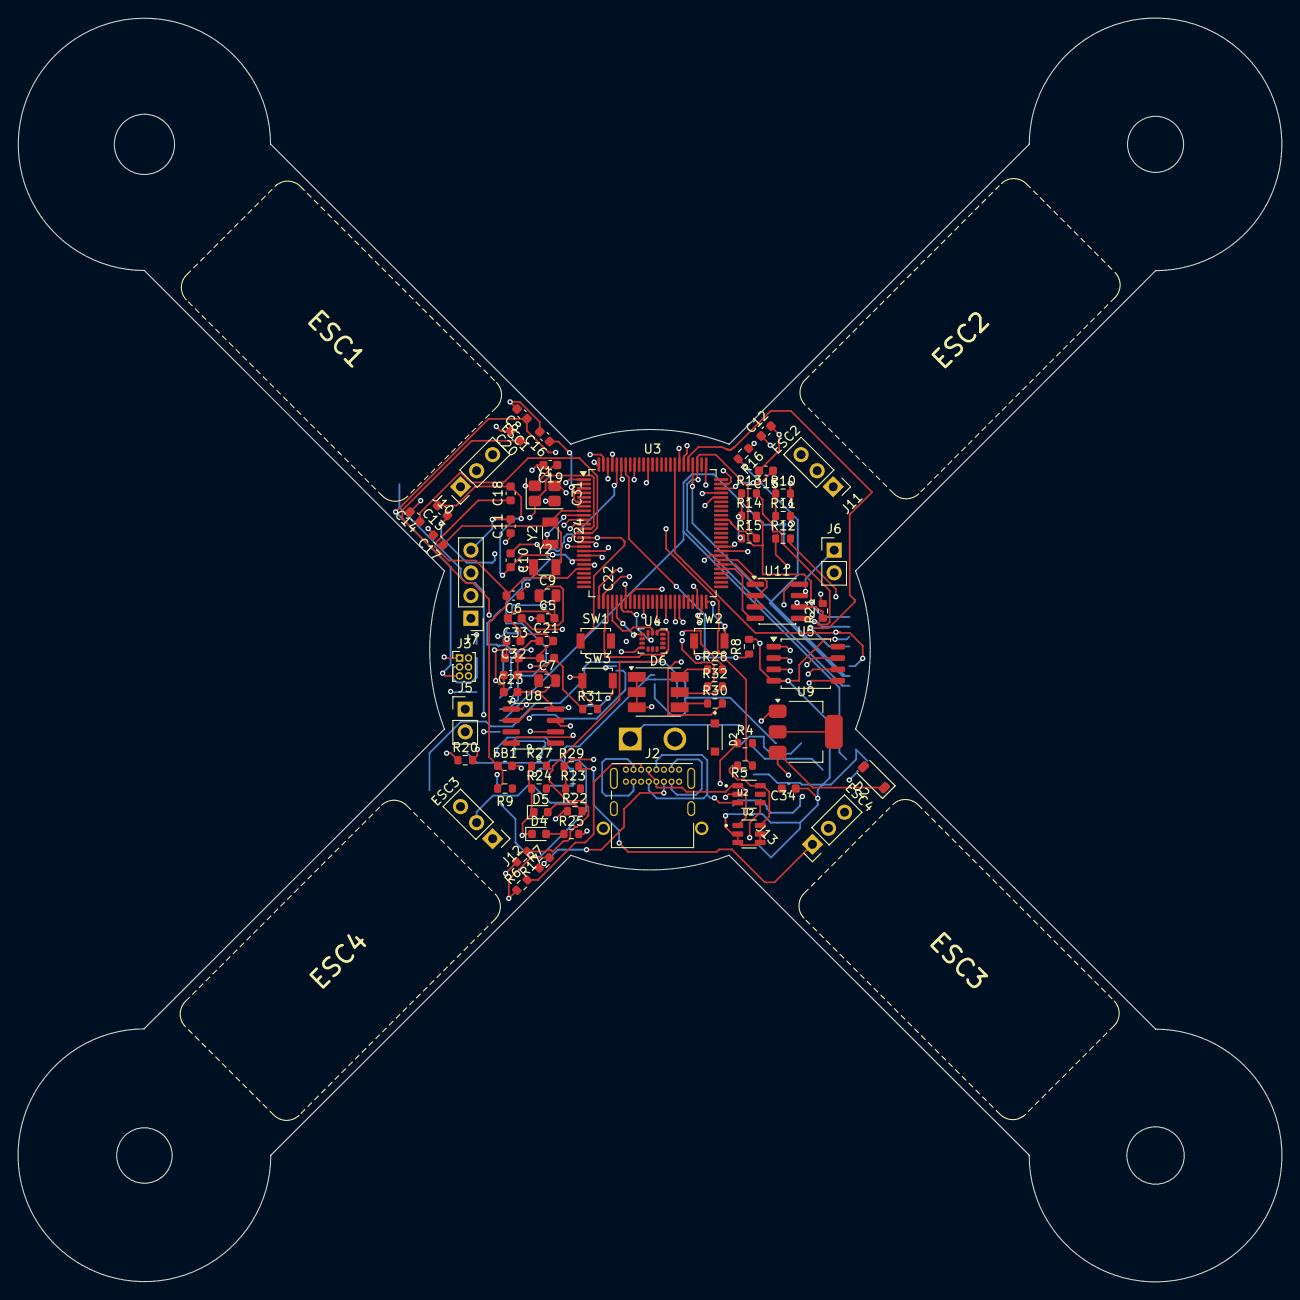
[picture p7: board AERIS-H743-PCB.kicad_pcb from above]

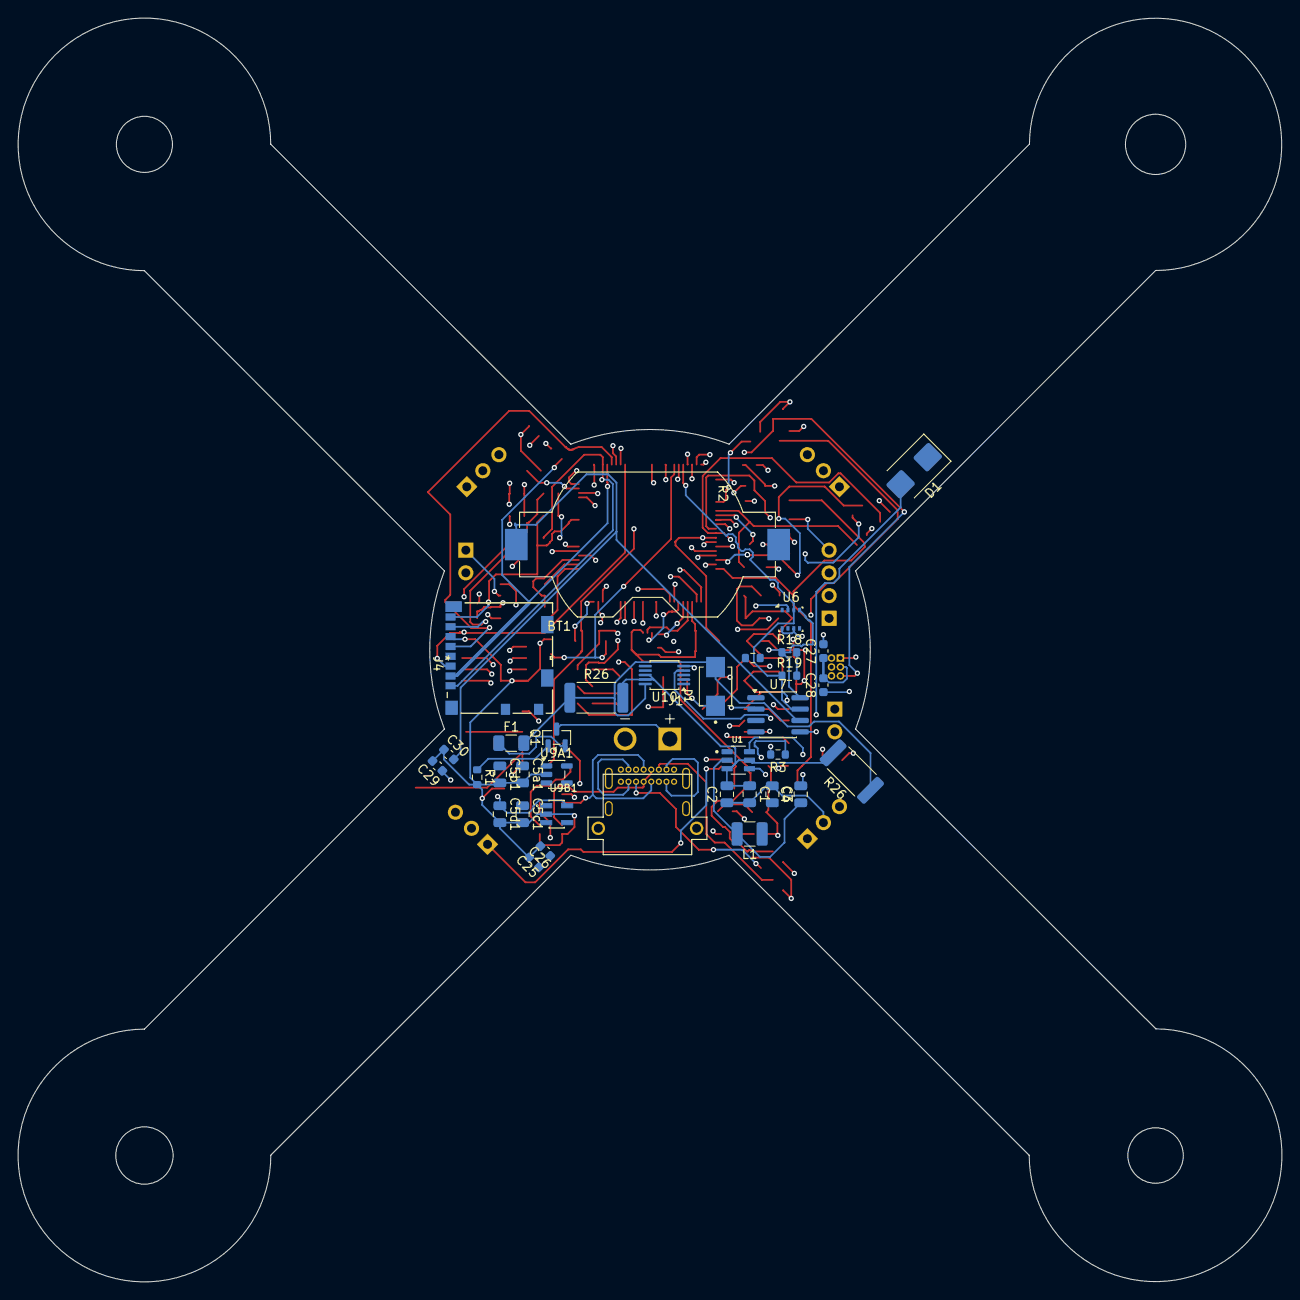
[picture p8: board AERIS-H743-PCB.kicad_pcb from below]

Board: 6 copper layers, 141.4 x 141.4 mm, 114 parts (35 on the bottom side), 83 nets.

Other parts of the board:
D1#2: D_TVS; D_SMB
D2#2: D_Schottky; D_SOD-123
R26#2: 20mohm; R_2512_6332Metric
U2#2: USBLC6-2SC6; SOT95P280X145-6N
U9: AMS1117-3.3; SOT-223-3_TabPin2
Y2#2: 32.768kHz; Crystal_SMD_3215-2Pin_3.2x1.5mm

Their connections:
/MCU_Core/PC14: Y2#2.1; also elsewhere on the board
/POWER SECTION/5V: D2#2.1 (K), U9.3 (VI)
/POWER SECTION/GND: D1#2.2 (A2), U9.1 (GND)
unnamed 66: U2#2.1; also elsewhere on the board
unnamed 73: U2#2.6; also elsewhere on the board
unnamed 74: R26#2.2; also elsewhere on the board
unnamed 81: R26#2.1; also elsewhere on the board

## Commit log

2026-08-04 solve issue of power sheet
    [AERIS-F411-PCB.kicad_sch, POWER.kicad_sch]
2026-08-07 Power_section_schematic update
    [POWER.kicad_sch]
2026-08-10 MCU Core ADDED
    [AERIS-F411-PCB.kicad_sch, MCU_Core.kicad_sch]
2026-08-11 Added Memory/Storage sheet
    [AERIS-F411-PCB.kicad_sch, MCU_Core.kicad_sch, Memory&Storage.kicad_sch]
2026-08-12 Sensor Sheet Updated
    [AERIS-H743-PCB.kicad_pcb, AERIS-H743-PCB.kicad_sch, MCU_Core.kicad_sch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]
2026-08-12 Ignore KiCad lock and local files
2026-08-14 all sheet available
    [AERIS-H743-PCB.kicad_sch, Communication.kicad_sch, Conn&Inc.kicad_sch]
2026-08-15 Updated and complete Schematic
    [AERIS-H743-PCB.kicad_pcb, AERIS-H743-PCB.kicad_sch, Communication.kicad_sch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]
2026-08-28 Edge Cut Made
    [AERIS-H743-PCB.csv, AERIS-H743-PCB.kicad_pcb, POWER.kicad_sch]
2026-08-28 PCB Design process 20% complete
    [AERIS-H743-PCB.kicad_pcb]
2026-08-28 Component Placement Done
    [AERIS-H743-PCB.kicad_pcb, POWER.kicad_sch]
2026-08-30 working Routing
    [AERIS-H743-PCB.kicad_pcb]
